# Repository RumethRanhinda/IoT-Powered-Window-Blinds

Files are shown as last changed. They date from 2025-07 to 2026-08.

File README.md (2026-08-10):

# LUMOS – IoT-Powered Automated Window Blinds

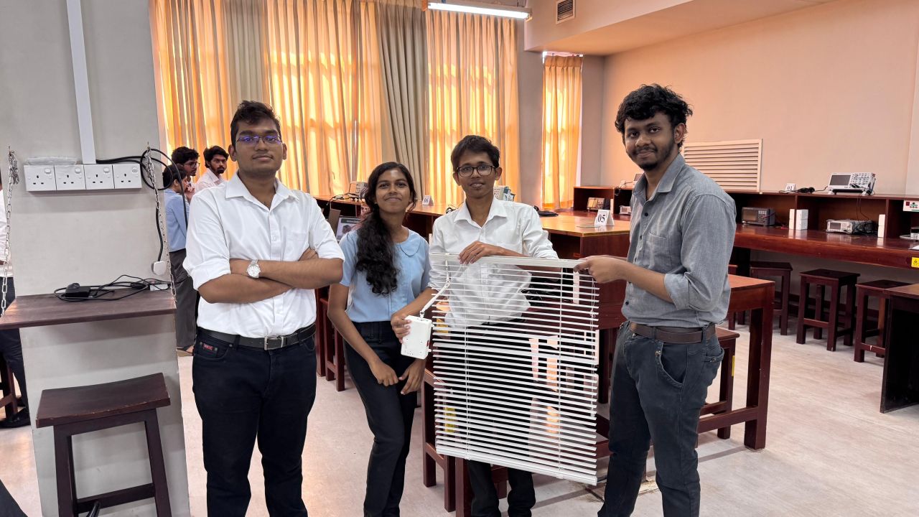
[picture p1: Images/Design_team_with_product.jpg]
Design_team_with_product







**LUMOS** is an automated, light-sensitive smart window blind adjustment system designed to optimize indoor ambient lighting autonomously. Engineered as an accessible and cost-effective alternative to expensive imported motorized blinds, LUMOS continuously monitors ambient lux levels and adjusts the blind tilt angle using a stepper motor and universal joint shaft drive mechanism. It features a Next.js 15 web dashboard with real-time controls, historical data dynamic graphs, and AI-driven insights.

Developed as part of the **EN1190 Engineering Design Project** at the Department of Electronic and Telecommunication Engineering, University of Moratuwa.

---

## Key Features

* **Dual-Sensor Light Averaging**: Uses two BH1750 digital ambient light sensors to compute average lux, preventing false adjustments triggered by temporary light spikes or transient shadows.
* **30-Second Adjustment Cycle**: Periodically evaluates indoor ambient light against user-defined room thresholds and drives the stepper motor to achieve optimal tilt.
* **Universal Joint Drive Mechanism**: A custom-designed 3D-printed connecting shaft featuring dual universal joints (u-joints) transfers motor torque at variable angles from the wall-mounted enclosure to the blind wand.

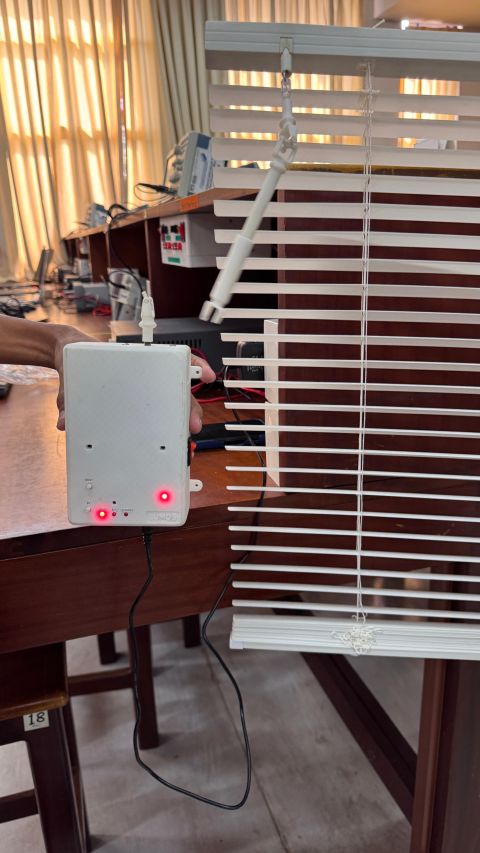
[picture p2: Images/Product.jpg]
Product
  
  
* **Dual Operating Modes**:
  * **Automatic Mode**: Autonomous light sensing and motor control based on target light intensity.
  * **Manual Mode**: Direct web app override using tilt position presets (Fully Open, Mostly Open, Half Closed, Mostly Closed, Fully Closed) or exact angle sliders.
* **IoT Web Dashboard**: Built with Next.js 15, Tailwind CSS, and ShadCN UI, providing real-time data visualizer, custom control toggles, and sleep mode scheduling.

---

## System Architecture

The overall system architecture consists of an ESP32 processing unit reading dual BH1750 sensors over I2C, driving a 28BYJ-48 stepper motor, and communicating bidirectionally with the Next.js web application over Wi-Fi.

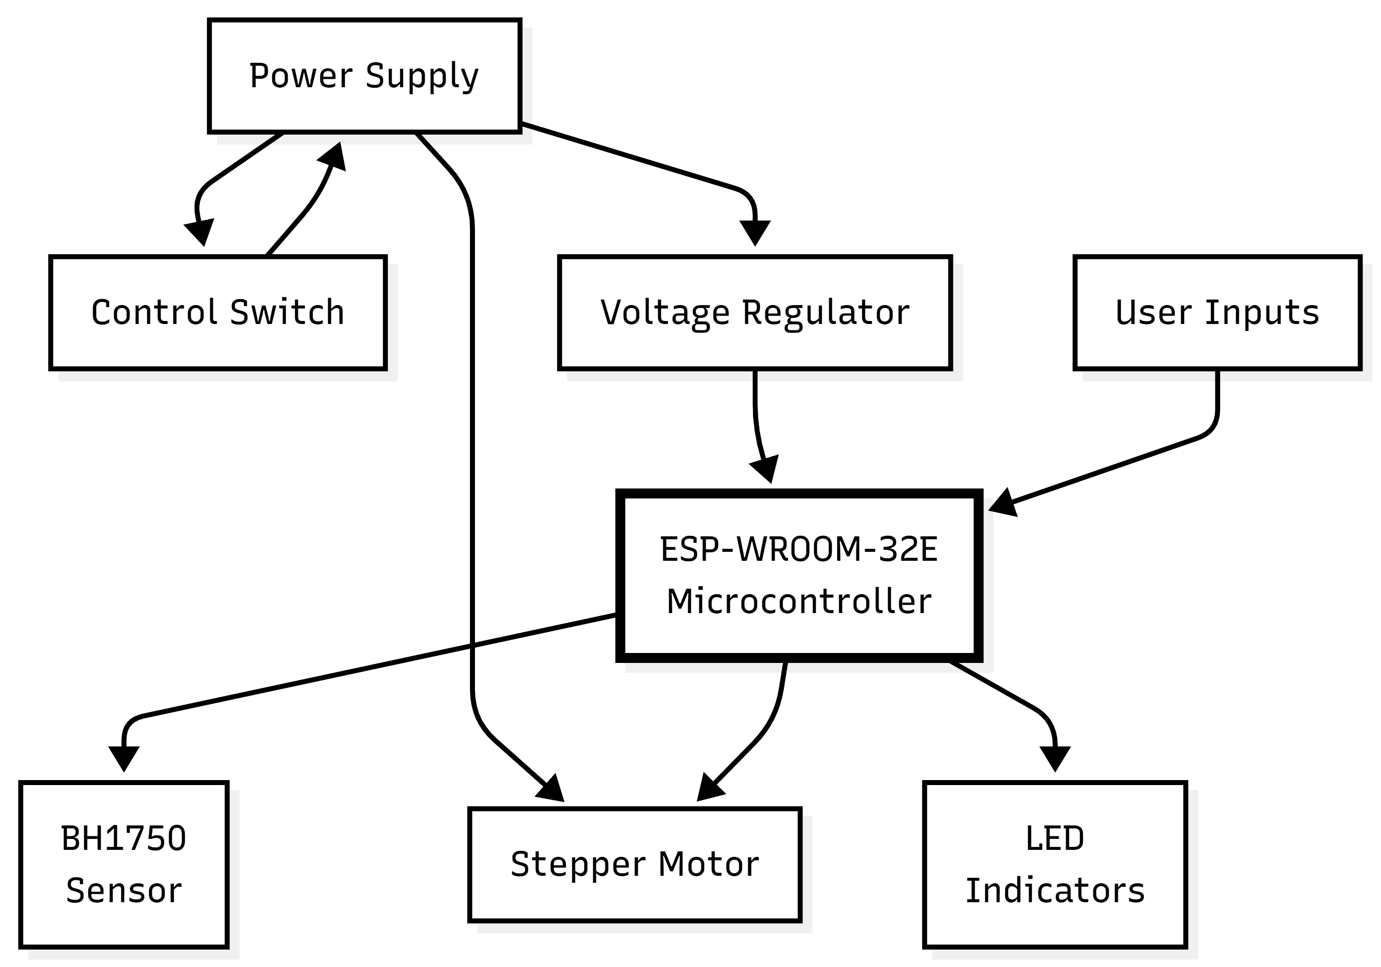
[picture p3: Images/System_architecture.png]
System-Architecture


---

## Hardware Specifications & PCB Design

The custom 2-layer PCB was designed using **Altium Designer** to integrate the ESP32 module, power conditioning components, sensor headers, and motor driving logic into a compact form factor.

| Component | Function / Description |
| :--- | :--- |
| **ESP-WROOM-32E** | Central microcontroller handling sensing, control algorithms, and Wi-Fi connectivity. |
| **BH1750 Sensors (x 2)** | Digital ambient light intensity sensors (Lux) connected via I2C. |
| **28BYJ-48 Stepper Motor** | Provides high-torque, precise angular control of the window blind tilt mechanism. |
| **Voltage Regulator Module** | Regulates 12V DC input down to 3.3V DC for the ESP32 and logic peripherals. |
| **12V Power Pack** | External AC-to-DC power adapter providing primary system power. |
| **Status LEDs & Switches** | Onboard diagnostic indicators (Power, Mode, Sensor State) and manual control buttons. |

### PCB Layout & Assembly
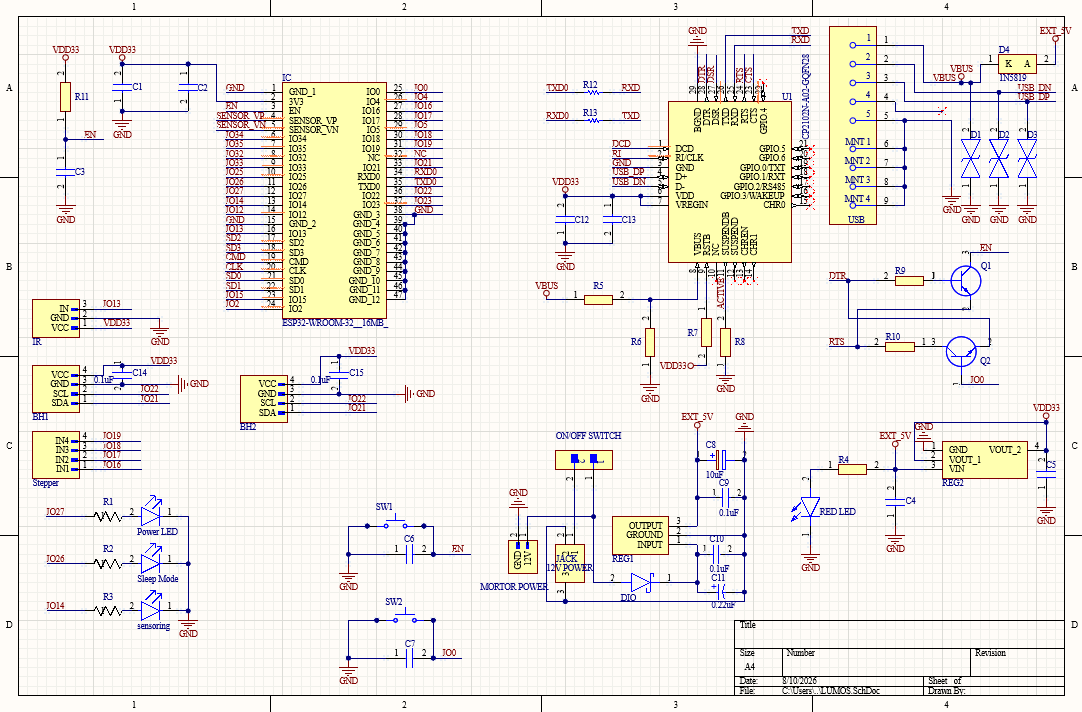
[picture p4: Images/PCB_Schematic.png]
PCB_Schematic

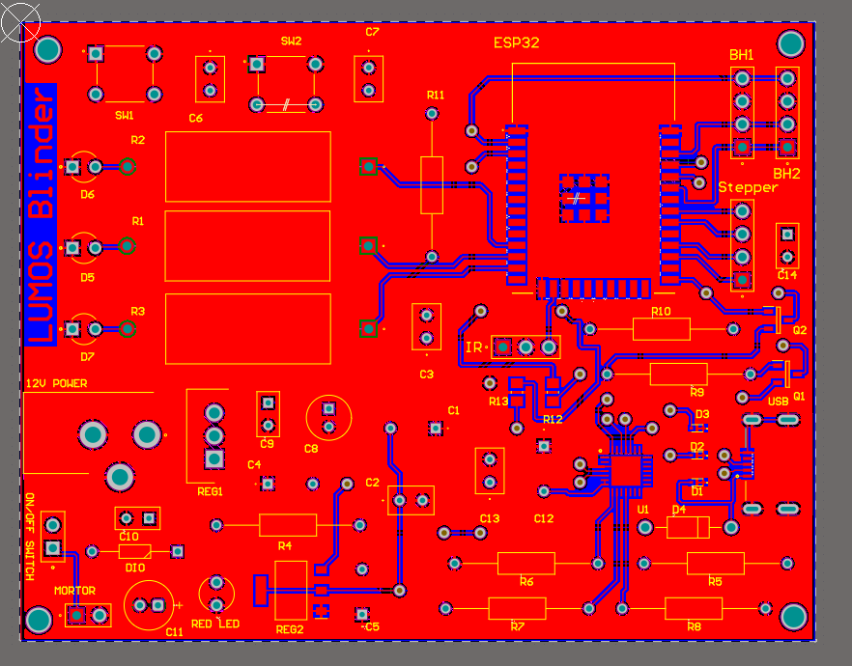
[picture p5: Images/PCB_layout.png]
PCB_layout

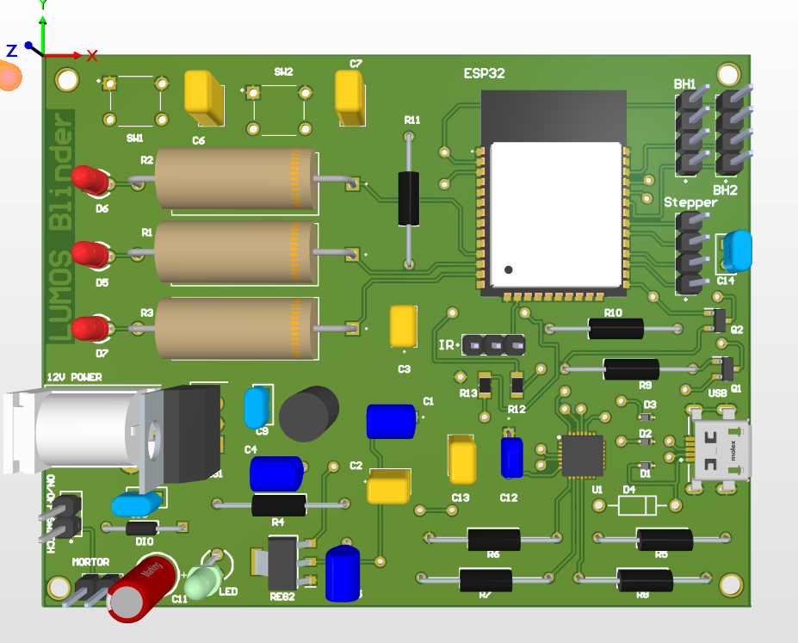
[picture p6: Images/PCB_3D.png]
PCB_3D


---

## Enclosure & Mechanical Design

The enclosure and output shaft mechanism were designed in **SOLIDWORKS** and 3D-printed using PLA.

* **Wall-Mountable Enclosure**: Compact 140 x 50 mm housing with dedicated cutouts for ambient light sensors, status LEDs, override buttons, and power connection.
* **Universal Joint Drive Shaft**: Flexible connecting mechanism utilizing dual u-joints to connect the motor inside the enclosure to the tilt wand on any standard window blind, accommodating variable mounting offsets.

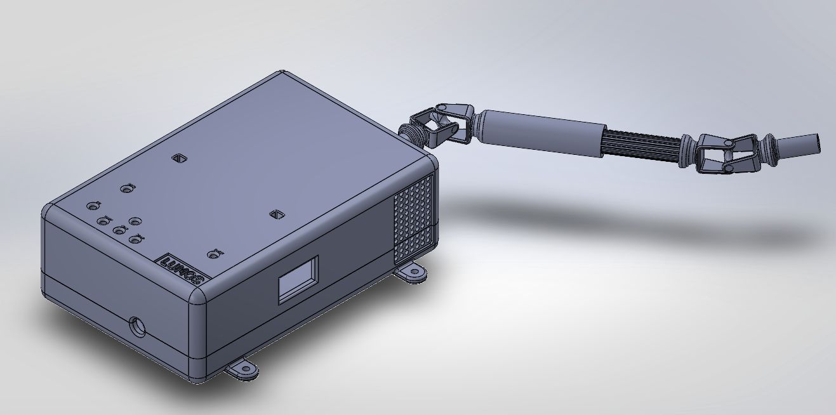
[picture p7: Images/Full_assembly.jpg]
Full_assembly

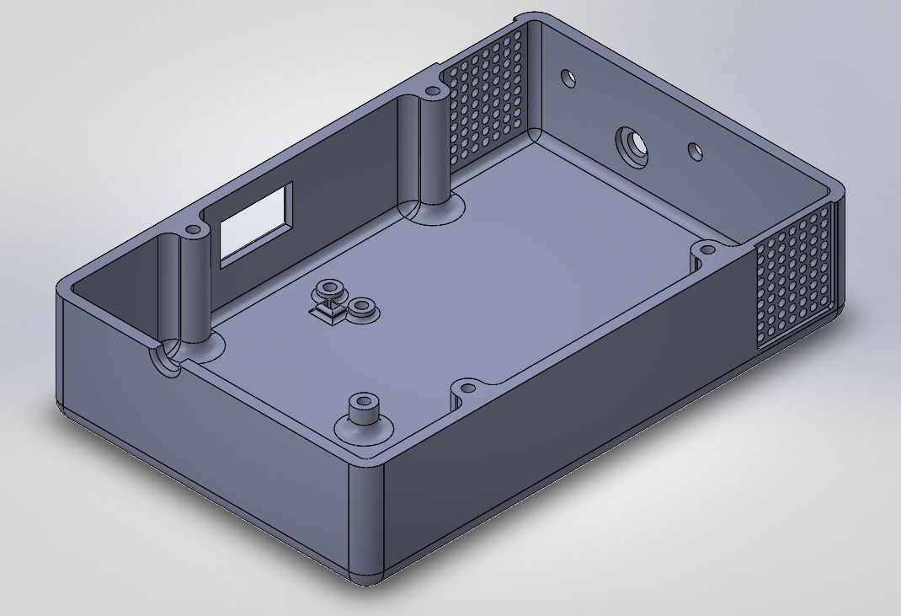
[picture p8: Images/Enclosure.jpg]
Enclosure

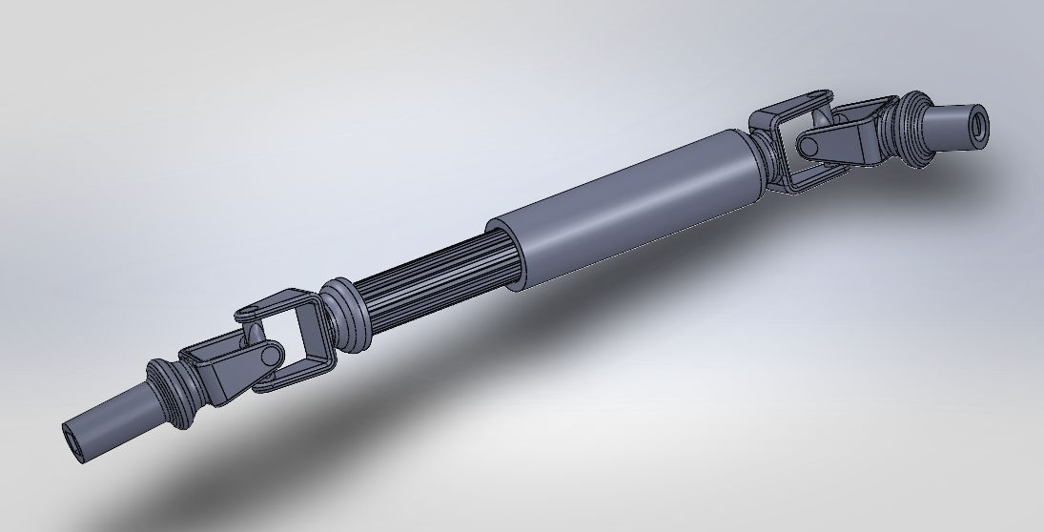
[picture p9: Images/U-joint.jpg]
U-joint


---

## Web Dashboard & Software Architecture

The web application provides interactive monitoring and configuration capabilities.

```text
lumos-web-app/
 ├── app/                  # Next.js 15 App Router pages & API routes
 ├── components/           # React 18 UI components (ShadCN UI)
 ├── lib/                  # Utilities, Firebase Studio & Genkit setup
 └── public/               # Static assets & dashboard icons
```

---

## Getting Started

### Firmware Setup (ESP32)
1. Open the firmware sketch in **Arduino IDE**.
2. Install necessary dependencies via Library Manager:
   * `BH1750`
   * `AccelStepper`
   * `WiFi` / `HTTPClient`
3. Select board **ESP32 Dev Module** and upload the firmware to the ESP32 chip.

---

## Future Improvements

* **Solar Power Integration**: Adding small solar panels and lithium battery storage to eliminate reliance on grid power.
* **Multi-Blind Synchronization**: Controlling and grouping multiple blind controllers across larger commercial spaces.
* **Expanded Blind Mechanism Compatibility**: Adapting mechanical adapters to support vertical blinds, roller shades, and curtain tracks.

---

## Authors & Acknowledgments

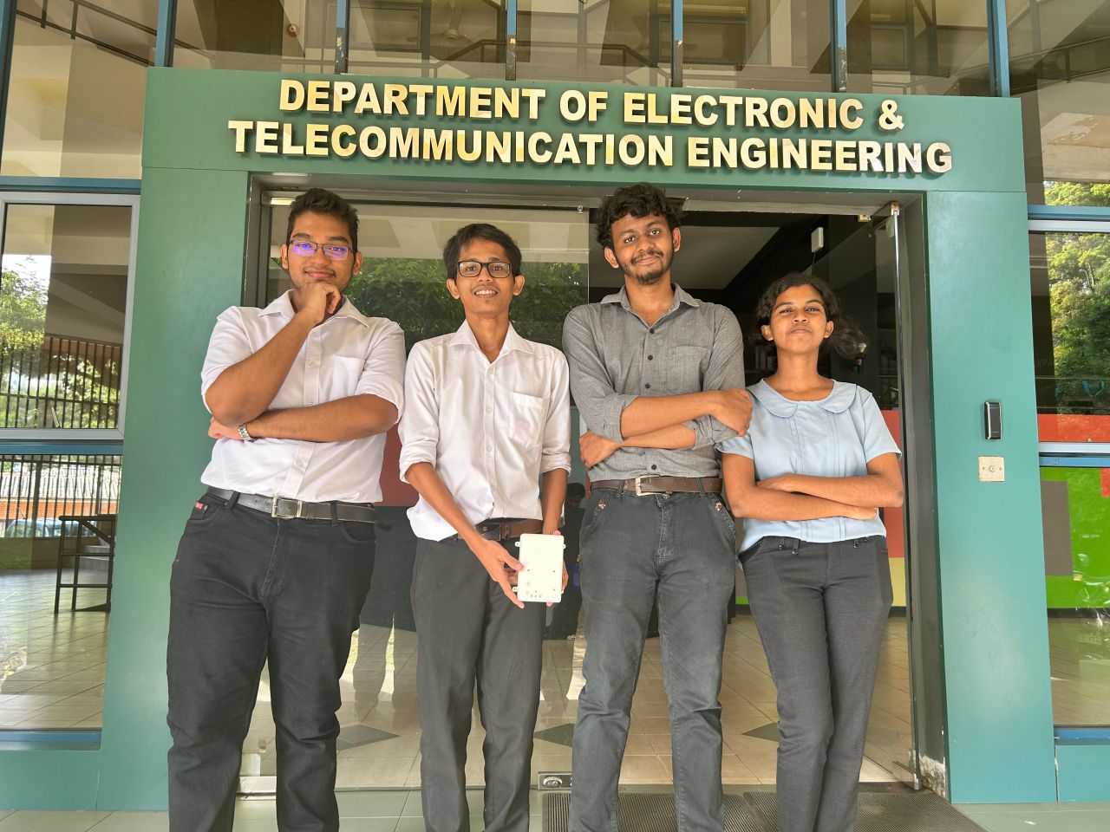
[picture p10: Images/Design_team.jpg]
Design_team


* **Team LUMOS** (Department of Electronic & Telecommunication Engineering, University of Moratuwa): *(From Left to Right)*  
  * Samarasinghe S.M.R.R. – Enclosure Design & Optimization, Mechanical CAD, Debugging
  * Eranga W.A.O. – Circuit & PCB Design, Microcontroller Programming, Web App Design
  * Gamage S.K. – Hardware Selection, Survey Analysis, Presentation
  * Tharushika G.K.E. – Product Assembly, Market Analysis, Costing

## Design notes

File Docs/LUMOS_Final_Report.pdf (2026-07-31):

## University of Moratuwa

## Faculty of Engineering

## Department of Electronic & Telecommunication

## Engineering

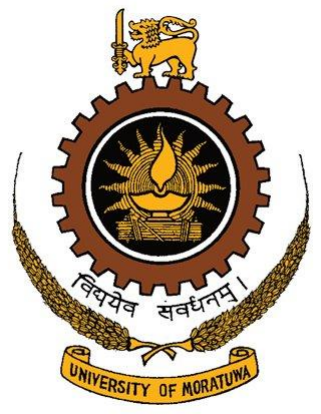
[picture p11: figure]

## EN 1190: Engineering Design Project

## Team LUMOS

## Automatic Window Blinds

### Group Members

Index No | Name
230175U | Eranga W.A.O.
230195F | Gamage S.K.
230566U | Samarasinghe S.M.R.R.
230636K | Tharushika G.K.E.

## Content

### 1. Problem Description

1.1. Problem
1.2. Expected Goal
1.3. Solution
1.4. Justification and Selection

### 2. Product Feasibility

2.1. Technical Feasibility
2.2. Hardware Feasibility
2.3. Software Feasibility

### 3. Product Applications 4. Product Specifications 5. Product Architecture

5.1. Block diagram

### 6. Enclosure Design

6.1. Initial Sketches
6.2. Final Sketch
6.3. Connecting Mechanism (Shaft)
6.4. Top View
6.5. Bottom View

### 7. PCB Design 8. Final Product 9. Market Analysis 10. Cost Analysis and Pricing

10.1. Project Budget with BOQ
10.2. Pricing Justification

### 11. Future Improvements 12. Contribution Report

## 1. Problem Description

### 1.1. Problem

Manual window blinds are still widely used in Sri Lanka, but they present several practical challenges. Elderly, disabled, and physically unwell individuals often struggle to adjust blinds on their own. In large-scale settings such as hotels, offices, and institutions with numerous windows, manual adjustment becomes a time-consuming and labor-intensive task. Additionally, in environments like greenhouses, laboratories, museums and material storage facilities, where maintaining ideal lighting conditions is crucial, manual blinds fail to provide consistent control.

Although motorized and automatic window blind systems with light sensors exist internationally, they are not manufactured locally in Sri Lanka. The limited options available in the local market are imported products that are often prohibitively expensive and not suited for widespread or affordable adoption. As a result, there is a clear gap in the availability of cost-effective, smart window blind solutions that fulfil local needs.

### 1.2. Expected Goal

Our goal is to provide a practical and accessible solution for individuals who face difficulties in manually operating window blinds, such as the elderly, disabled, or physically unwell, as well as for environments where efficient light control is essential. We aim to simplify and automate the process of adjusting blinds using light-sensing technology, allowing users to maintain optimal indoor lighting conditions effortlessly, without the need for manual labor, technical expertise, or expensive infrastructure

### 1.3. Solution

Our solution is an Automatic Light-Sensitive Window Blind System designed to adjust the tilt of blinds based on the ambient light level in the room. During installation, users can specify their preferred lighting levels for each room, accommodating different needs such as workspaces, bedrooms, or specialized environments like greenhouses. The system then operates autonomously, maintaining optimal lighting without the need for manual adjustment. Unlike traditional systems, our product is designed to be affordable and user-friendly. We also offer comprehensive after-sales support, including assistance with installation, routine maintenance, and technical guidance to ensure smooth operation over time, which is impossible to get when shipping from overseas.

### 1.4. Justification of Selection

The lack of accessible and reliable automated window blind systems presents a practical issue in Sri Lanka, especially for individuals with physical limitations and in environments where precise lighting control is essential. Currently, the market relies heavily on imported motorized blind systems, which are not only expensive but also prone to technical failures. Moreover, these systems are often limited to premium establishments and are largely unavailable to the general public.

Through discussions with local window blind sellers and industry professionals, we identified a significant gap in the Sri Lankan market for an affordable, durable, and locally supported automated window blind solution. Sellers expressed a willingness to collaborate, noting that a reliable, cost-effective alternative would benefit both residential and commercial customers. Our proposed system directly addresses these concerns by offering a customizable, light-sensitive solution backed by local after-sales support.

## 2. Product Feasibility

### 2.1. Technical Feasibility

We have successfully developed a technically viable prototype using reliable and accessible components. To measure indoor light intensity, we used two BH1750 light sensors to obtain an average reading, which helps minimize the impact of sudden light spikes and ensures accurate decision-making. The system is controlled by an ESP-WROOM-32E microcontroller, which processes sensor inputs and adjusts the blinds accordingly.

For actuation, we utilized the 28BYJ-48 stepper motor, which precisely controls the angle of the window blinds. The system is powered through an AC supply; regulated via a 12V power pack to ensure consistent and stable performance and a voltage regulator to maintain a stable voltage at 3.3V. All necessary components were acquired, and the integration was completed successfully. The enclosure and the connecting shaft were 3D printed using PLA. We designed and assembled the circuit ourselves, including custom soldering work and mechanical alignment for the blind mechanism.

### 2.2. Hardware Feasibility

The hardware components we used are

- ESP-WROOM-32E Chip
- BH1750 Light Intensity Sensors
- Voltage Regulator Module
- Stepper Motor 28BYJ-48
- LED Indicators
- 12V Power Pack

### 2.3. Software Feasibility

Software | Programming Language | Purpose
Arduino | C++ | To Program the ESP 32 chip
SOLIDWORKS | - | To Design the Enclosure
Firebase Studio | React | To Create the Web App

## 3. Product Applications

The main application of the automatic light-sensitive window blind system is to maintain optimal indoor lighting conditions without manual intervention. By continuously monitoring the ambient light levels using dual BH1750 sensors, the system automatically adjusts the tilt angle of the blinds to match the user-defined brightness preferences set during installation. This ensures a consistent and comfortable lighting environment across different rooms, while also improving energy efficiency and reducing the need for frequent manual adjustments, especially beneficial for elderly, disabled individuals, and large-scale settings such as hotels and offices.

LUMOS Blinder Web Application

The LUMOS Smart Blind Web application is connected to the device via Wi-Fi. It displays real-time ambient light levels and blind angles through an interactive dashboard. Users can switch between automatic and manual control modes, view historical data through dynamic charts, and receive AI-generated insights about lighting patterns.

The app also allows configuration of system settings like sensing intervals and includes a responsive UI with mock authentication for user-specific access.

Core Technologies

- Frontend Framework: Next.js 15 with the App Router, enabling a modern, server-first web application with optimized performance.
- UI Library: React 18 for building interactive and stateful user interface components.
- Styling: Tailwind CSS for a utility-first styling approach, combined with ShadCN UI for a pre-built, accessible, and themeable component library.
- Artificial Intelligence: Google's Genkit framework to integrate generative Al, powering the "Al Assistant" feature for data analysis and insights.
- Language: TypeScript for type safety, improved developer experience, and more maintainable code.

Key Functionalities

- Real-time loT Dashboard: The application features a live dashboard that simulates real-time data from lot sensors (lux sensors) and actuators (window blinds).
- Dynamic Data Visualization: A responsive line chart visualizes historical sensor and blind angle data, updating dynamically to reflect system changes.
- Dual Control Modes:
1. Automatic Mode: The system intelligently adjusts the blind angle based on simulated ambient light levels, mimicking a real- world automated smart home device.
2. Manual Mode: Users can disable the automatic system and take direct control of the blinds using a slider and preset position buttons.
- Al-Powered Insights: An "Al Assistant" uses a Genkit flow to analyze the recent history of sensor data and blind movements, providing users with easy-to-understand summaries and insights about the system's behavior.
- System Configuration: Users can configure system parameters, such as the Sensing Interval, to simulate changing the device's data reporting frequency. A "Sleep Mode" toggle is also included as a UI element.
- Responsive and Modern UI: The user interface is designed to be fully responsive, adapting seamlessly to desktop, tablet, and mobile screen sizes. It also includes a dark/light mode theme toggle for user preference.
- Mock Authentication: The app includes a simulated user authentication flow to demonstrate how UI elements (like controls) can be enabled or disabled based on user signin status.

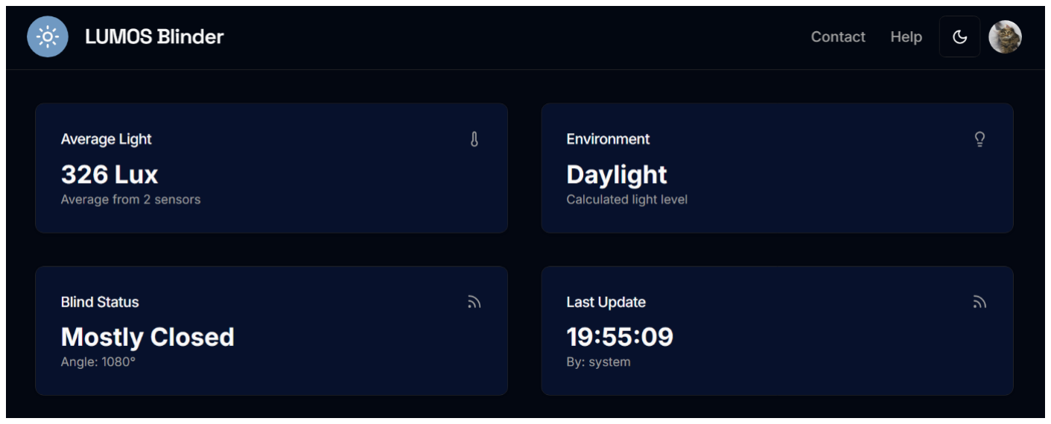
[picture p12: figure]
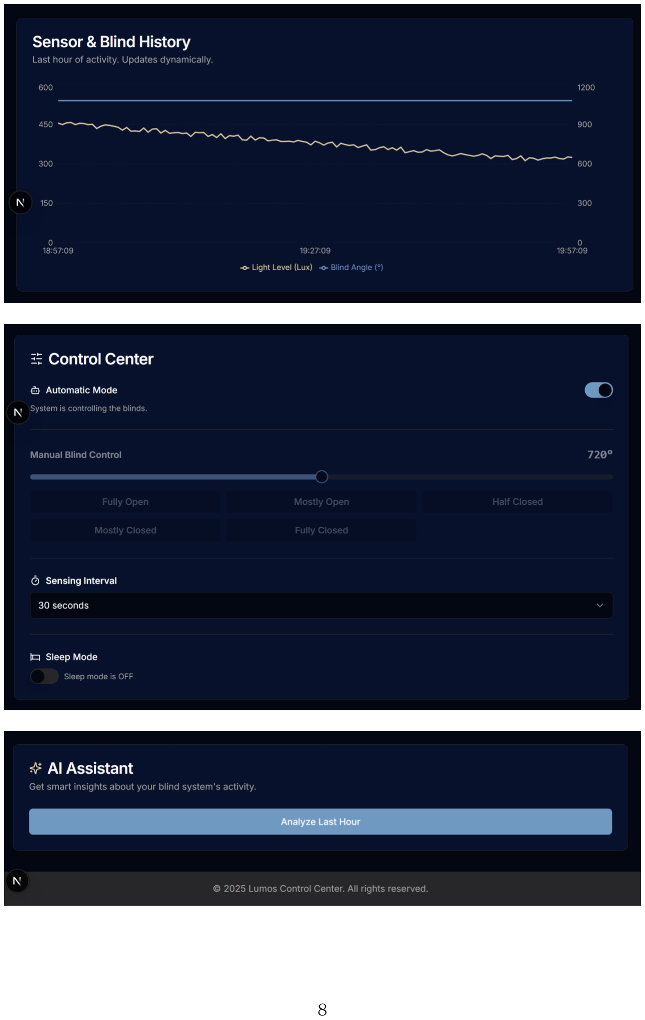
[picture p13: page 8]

## 4. Product Specifications

- Type: Automatic Window Blind Controller with Light Sensors
- Synonyms: Smart Blind Controller, Light-Sensitive Blinds, Motorized Smart Blind Adjustment System
- Control Method: Light Intensity-Based Automatic Adjustment
- Power Supply: 12V DC via AC Power Pack
- Dimensions: 140x50 mm
- Weight: 150g
- Connectivity: Wired
- Installation: Wall-Mountable Control Box
- User Settings: Customizable Brightness Thresholds per Room at Installation

## 5. Product Architecture

- Power Supply - The system is powered through a 12V DC supply using an external AC power pack.
- ESP 32 chip - The ESP-WROOM-32E microcontroller is used to process real time light intensity data from the sensors and control the stepper motor accordingly. It handles averaging, decision making logic, and motor control.
- Voltage Regulator - Regulates the input voltage to 3.3V for the ESP32 to operate reliably.
- Light Sensors - Two BH1750 digital light sensors are used to measure indoor light intensity. Averaging the readings from both sensors helps avoid errors caused by sudden light fluctuations and improves the accuracy of blind adjustment.
- Motor - The 28BYJ-48 stepper motor is used to adjust the tilt angle of the window blinds smoothly and precisely.
- Web App – Connected to the device via Wi-Fi, displays light levels and blind angles, and allows the users to switch between manual and automatic control modes.
5.1. Block Diagram

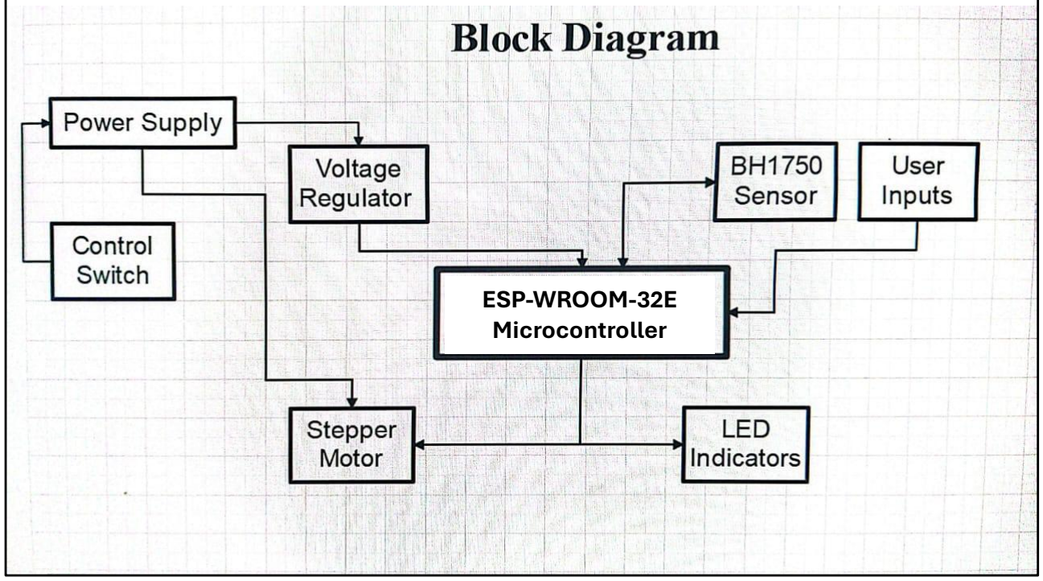
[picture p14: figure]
ESP-WROOM-32E Microcontroller

## 6. Enclosure Design

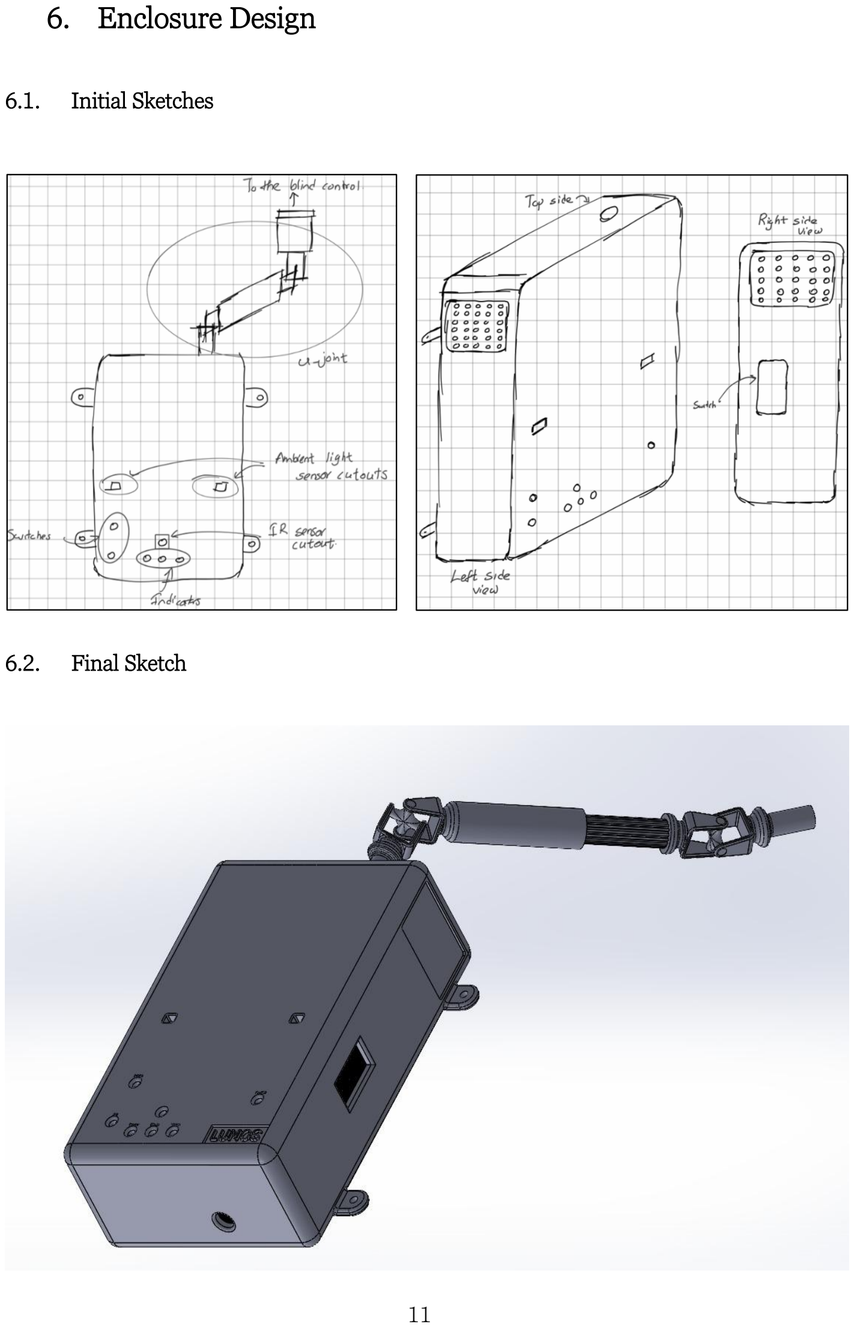
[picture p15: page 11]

6.1. Initial Sketches
6.2. Final Sketch

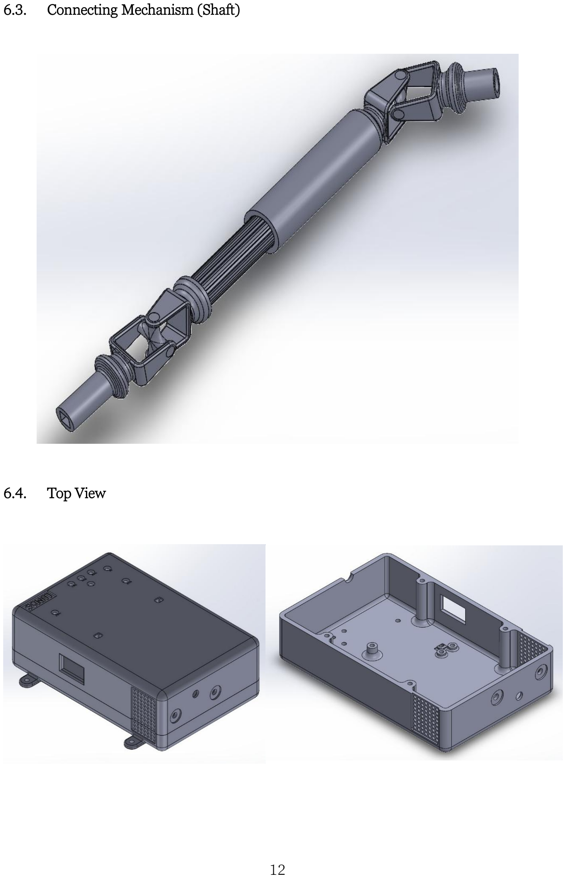
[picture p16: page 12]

6.3. Connecting Mechanism (Shaft)
6.4. Top View

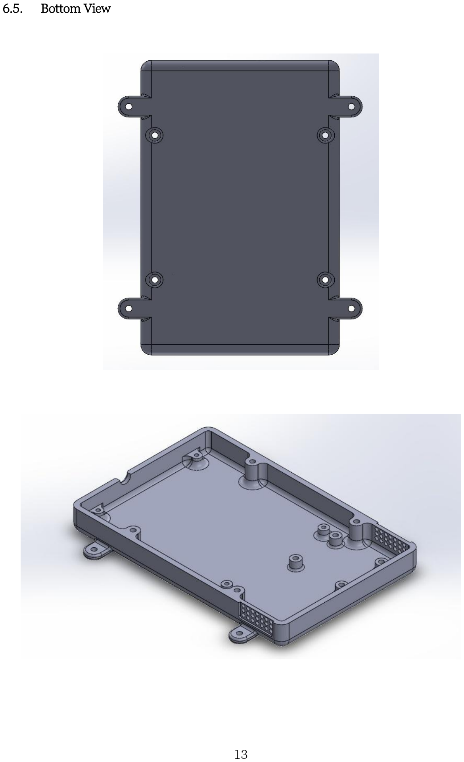
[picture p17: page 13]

6.5. Bottom View

## 7. PCB Design

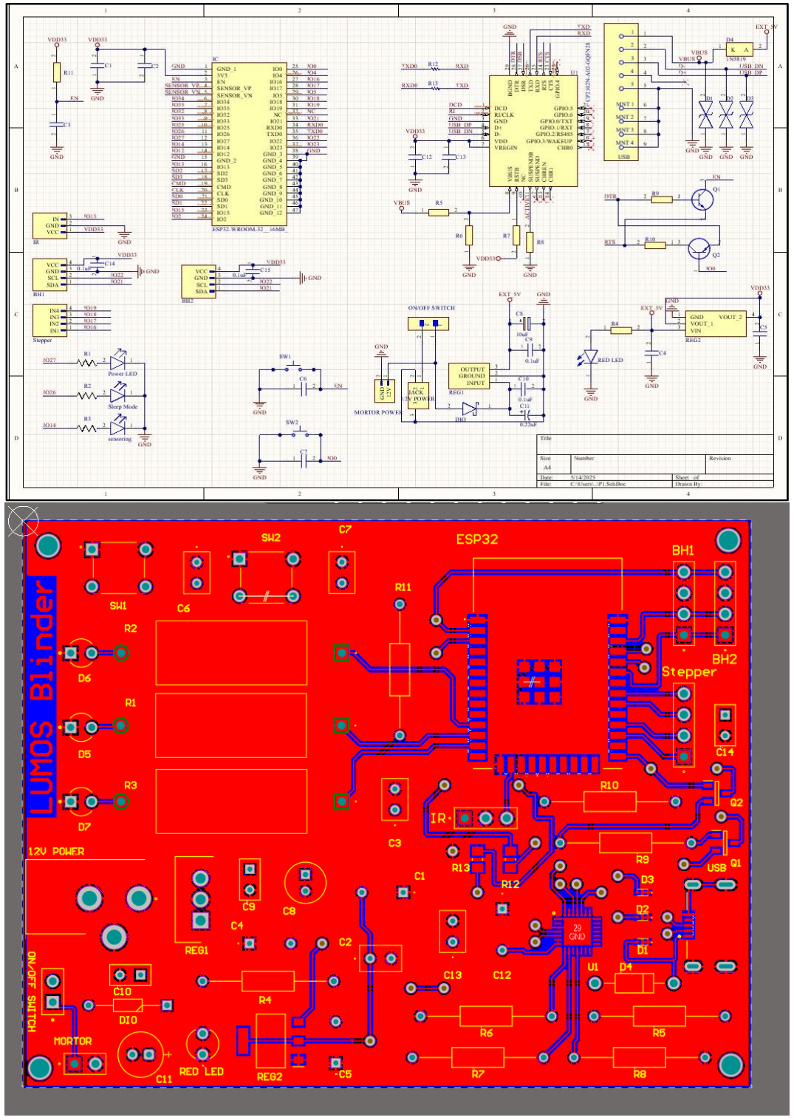
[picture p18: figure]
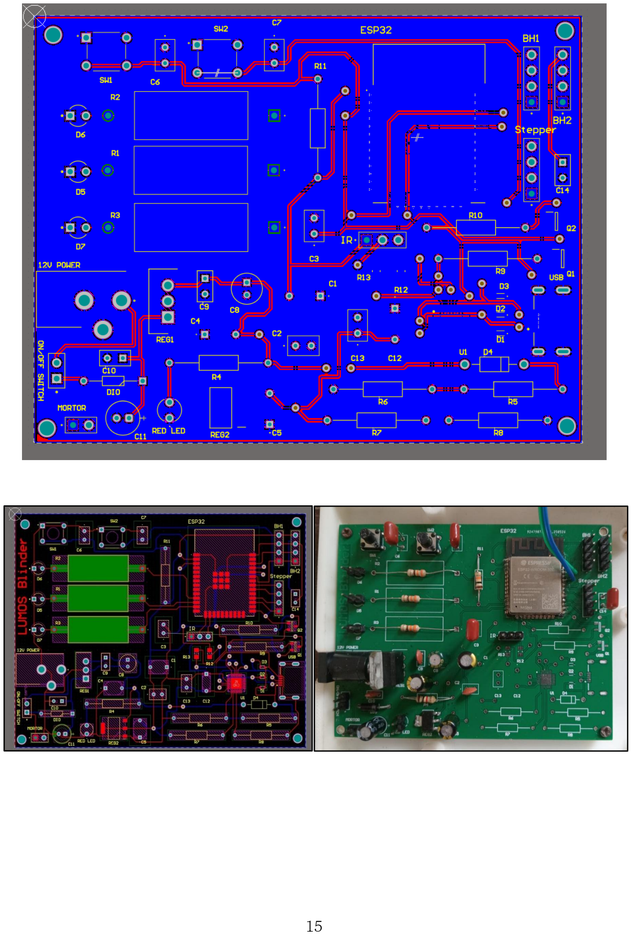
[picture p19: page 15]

## 8. Final Product

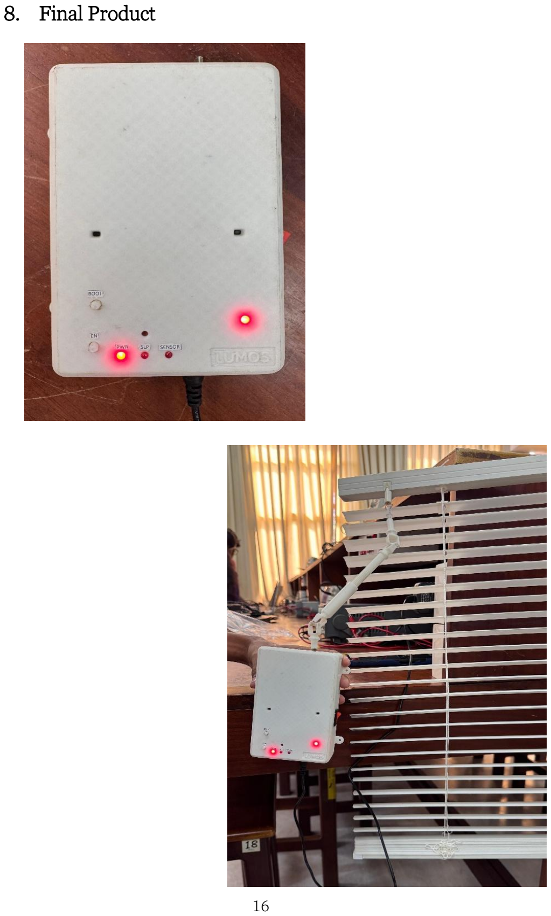
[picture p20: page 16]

## 9. Market Analysis

The smart blind automation market is gaining momentum globally due to increasing demand for energy efficiency, convenience, and smart home integration. Automated blind systems equipped with light sensors offer benefits such as optimizing natural lighting, reducing air conditioning use, and improving indoor comfort, all without user intervention. These systems are particularly useful in homes, offices, hospitals, and hotels, and also support accessibility for elderly or disabled individuals who may find manual blind operation difficult.

Our target audience includes environmentally conscious homeowners, tech-savvy consumers, corporate offices, hospitality businesses, and interior designers who seek modern, minimal-effort solutions. Possible business models for our product include directto-consumer sales, partnerships with hardware retailers and interior design firms, and even customized B2B deals for bulk deployment in institutions like hotels or hospitals.

However, we identified that there are no local manufacturers offering such systems in Sri Lanka, despite the rising interest in home automation. As a result, consumers must rely on international sellers, with base prices starting around LKR 21,000, but reaching up to LKR 33,000 to 36,000 after adding shipping and customs fees. Additionally, most of these imported products lack local warranty, maintenance, or after-sales service—resulting in inconvenience and higher lifetime costs.

This clear market gap highlights a strong opportunity for a locally developed, cost-effective blind automation solution with light sensoring that can be easily installed without replacing existing blinds. Challenges such as educating the public, building brand credibility, and competing with well-established global brands remain, but overcoming these barriers will be essential for capturing a significant share of this emerging market in Sri Lanka.

## 10. Cost Analysis and Pricing

10.1. Project Budget with BOQ
EXPENSE | Unit Price (Rs.) | Quantity | COST (Rs.)
Enclosure | 4,850.00 | 1 | 4,850.00
PCB | 3,360.00 | 1 | 3,360.00
ESP-WROOM-32E Chip | 1,000.00 | 1 | 1,000.00
Stepper Motor 28BYJ-48 | 600.00 | 1 | 600.00
BH1750 Sensors | 125.00 | 2 | 250.00
RLC components & Wiring | | | 400.00
Connector Shaft Mechanism | 750.00 | 1 | 750.00
Voltage Regulator + USB module | | | 500.00
12V Power Pack | 500.00 | 1 | 500.00
Misc. | | | 200.00
TOTAL | | | 12,410.00
10.2. Pricing Justification

The selling price for the product was determined by first calculating the manufacturing cost, which totals approximately Rs. 12,410 per unit. This includes all electronic components, motor, power supply, enclosure, and assembly. A reasonable markup was then applied to ensure profitability, after-sales service capability, and to account for future reductions in cost through mass production.

Considering these factors, the estimated selling price was set at Rs. 18,000 to Rs. 20,000, which remains significantly lower than the Rs. 33,000–36,000 required to import similar products. This pricing provides customers with savings of up to Rs. 20,000, while also offering local support and maintenance—something that imported alternatives lack. This ensures both affordability and long-term usability for Sri Lankan consumers.

## 11. Future Improvements

Introduction to Solar Power for Eco-Friendliness

Implementing solar panels to power the system, reducing dependence on grid electricity and promoting sustainability.

Integration of IoT Features

Adding Wi-Fi or cloud connectivity for remote control, real-time monitoring, and integration with smart home systems.

Multiple Blind Synchronization for Efficiency

Enabling control of multiple blinds simultaneously to maintain uniform lighting across large rooms or buildings.

Design Configurations for Other Types of Blinds

Adapting the system to support vertical blinds, roller blinds, and curtain mechanisms for broader compatibility

## 12. Contribution Report

Member | Tasks
Eranga W.A.O. (230175U) | Circuit & PCB Design Microcontroller Programming & Testing Web App Design
Gamage S.K. (230195F) | Product Idea, Hardware Selection Survey Analysis & Presentation
Samarasinghe S.M.R.R. (230566U) | Enclosure Design & Optimization Product Testing & Debugging
Tharushika G.K.E. (230636K) | Product Assembly & Testing Market Analysis and Budget Calculation

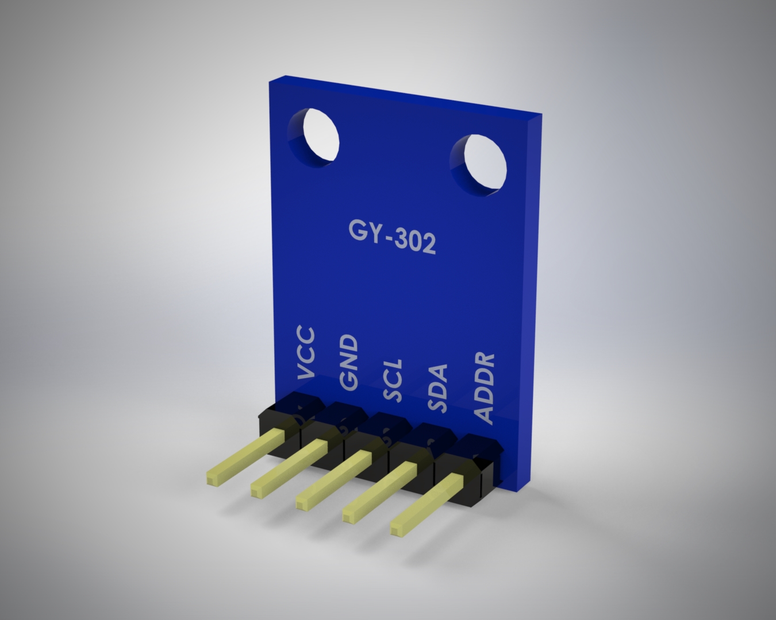
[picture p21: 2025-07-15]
SOLIDWORKS Files/Enclosure/bh1750-module/photos/Rear.jpg

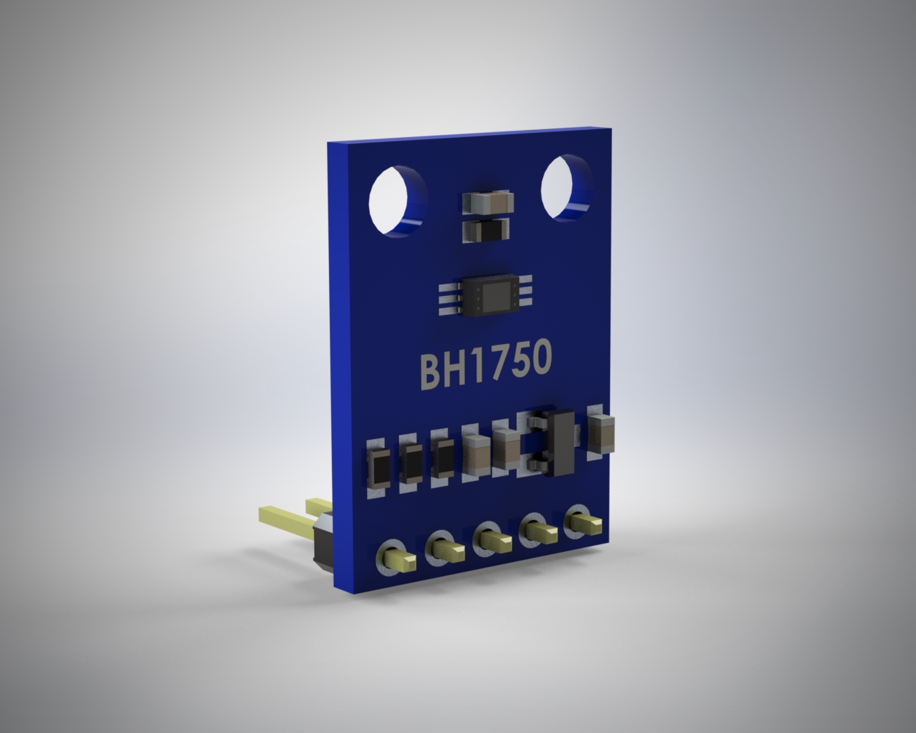
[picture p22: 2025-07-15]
SOLIDWORKS Files/Enclosure/bh1750-module/photos/Front.jpg

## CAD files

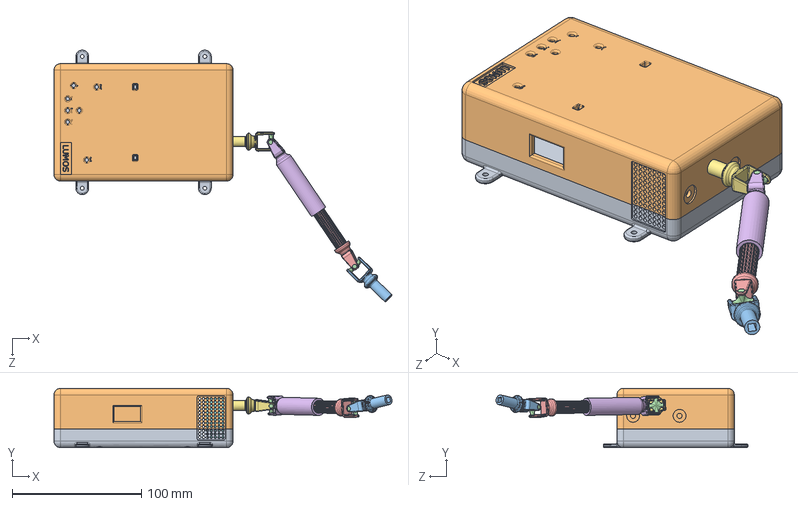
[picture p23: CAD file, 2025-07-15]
SOLIDWORKS Files/Full Assembly.SLDASM
261.9 x 46.0 x 195.1 mm
enclosurebottom
enclosuretop
rwhubshaft2
ujoint x 2
rwinnershaft
rwoutershaft
rwsprocketshaft
28BYJ-48

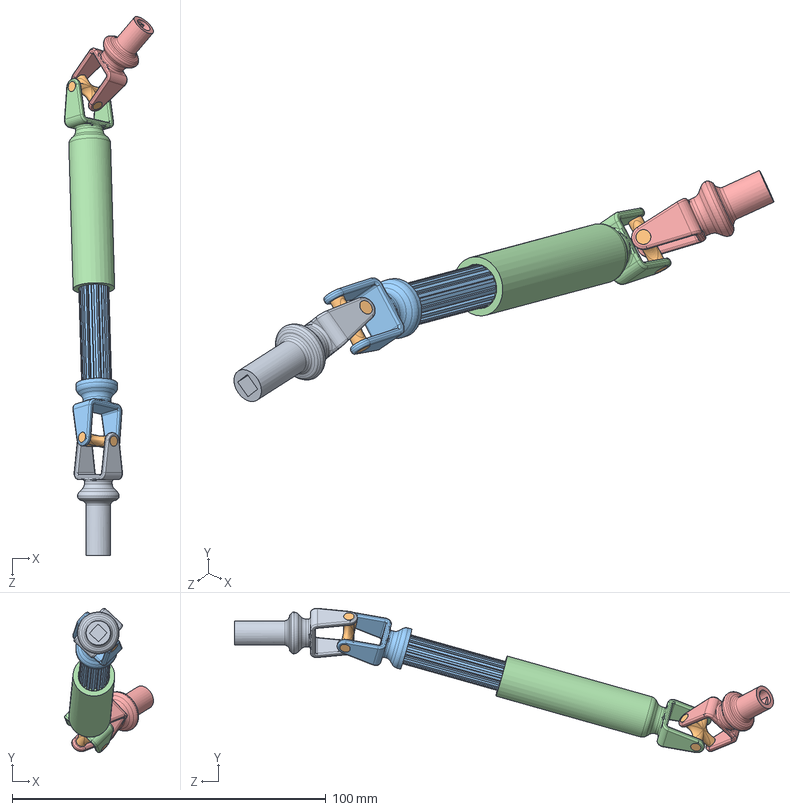
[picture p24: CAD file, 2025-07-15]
SOLIDWORKS Files/U-shaft/pivotslidingshaft-Assembly.SLDASM
28.4 x 46.0 x 171.9 mm
rwhubshaft2
ujoint x 2
rwinnershaft
rwoutershaft
rwsprocketshaft

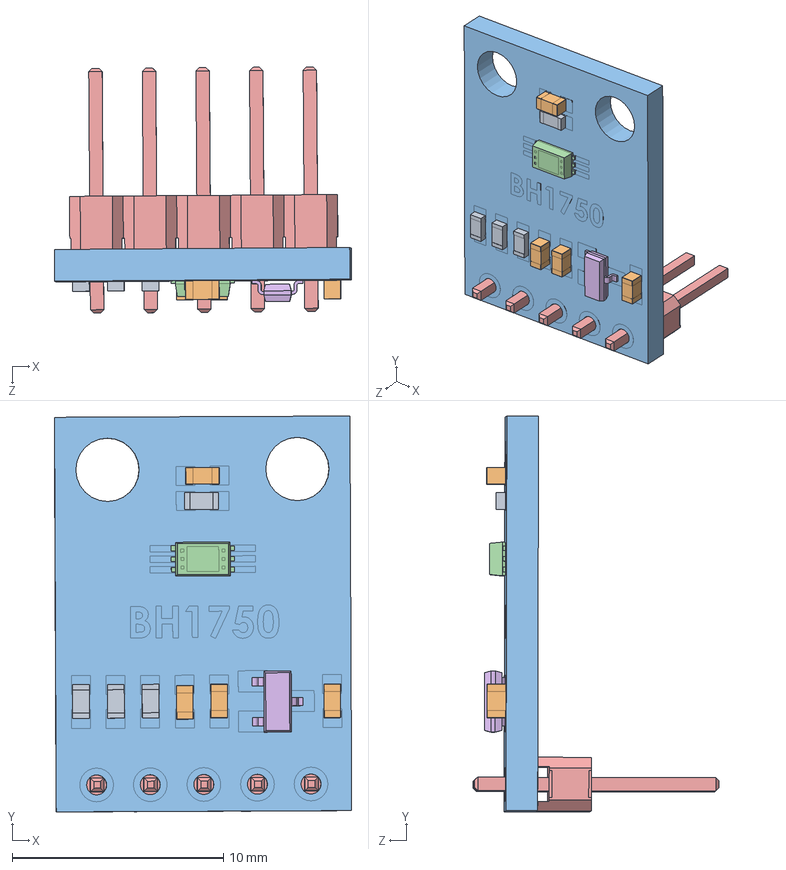
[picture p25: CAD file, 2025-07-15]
SOLIDWORKS Files/Enclosure/bh1750-module/Assign/BH1750_with_connector.SLDASM
14.1 x 18.8 x 11.7 mm
r_0603 x 4
cap_0603 x 4
BH1750_board
BH1750
PLS-5
SOT-23-3

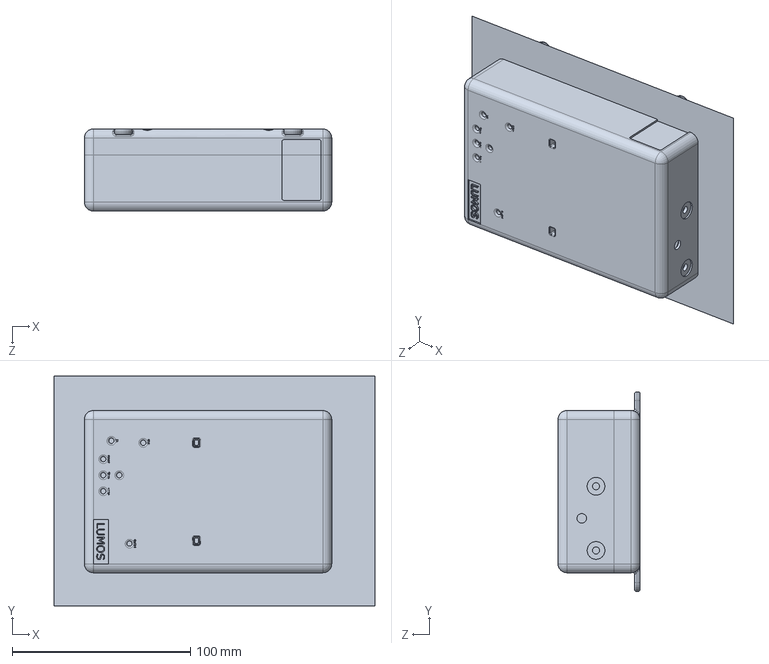
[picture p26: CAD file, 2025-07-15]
SOLIDWORKS Files/Enclosure/Enclosure-Full Assembly.SLDASM
180.0 x 128.9 x 46.0 mm

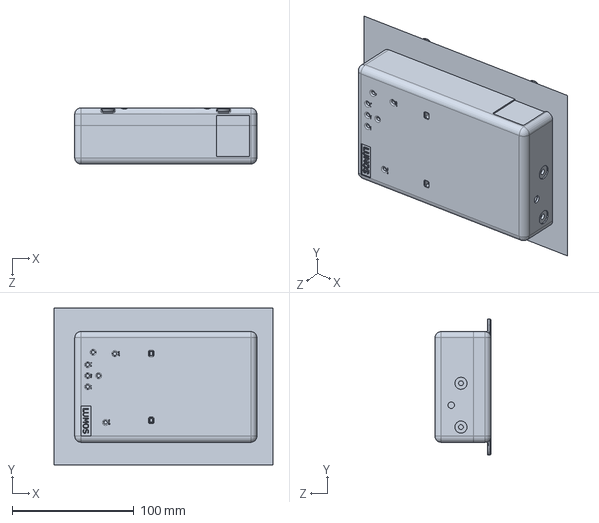
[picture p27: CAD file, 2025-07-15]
SOLIDWORKS Files/Enclosure/Enclosure_whole.SLDPRT
180.0 x 128.9 x 46.0 mm

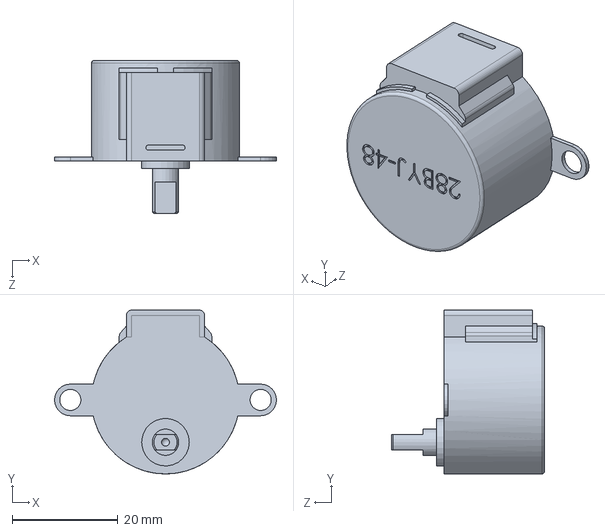
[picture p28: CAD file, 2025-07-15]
SOLIDWORKS Files/Enclosure/28byj-48-4-stepper-motor/28BYJ-48.SLDPRT
42.0 x 31.0 x 29.0 mm

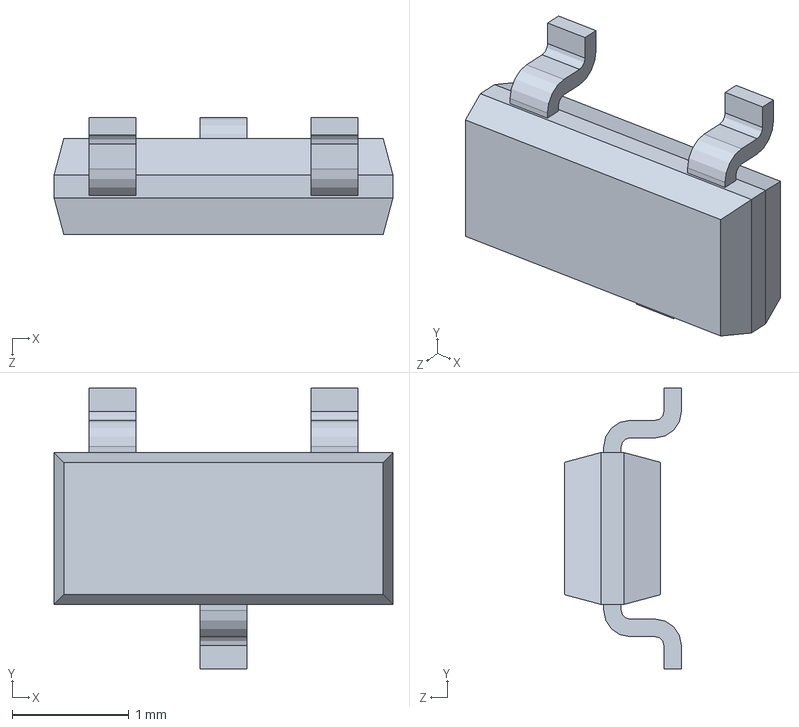
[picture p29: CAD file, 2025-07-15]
SOLIDWORKS Files/Enclosure/bh1750-module/Assign/SOT-23-3.SLDPRT
2.90 x 2.40 x 1.00 mm

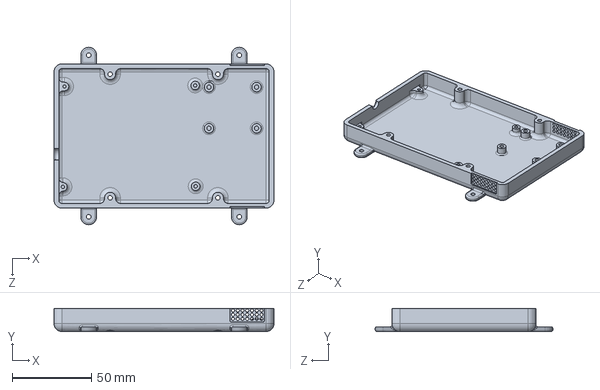
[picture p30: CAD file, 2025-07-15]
SOLIDWORKS Files/Enclosure/enclosurebottom.SLDPRT
138.8 x 14.5 x 112.0 mm

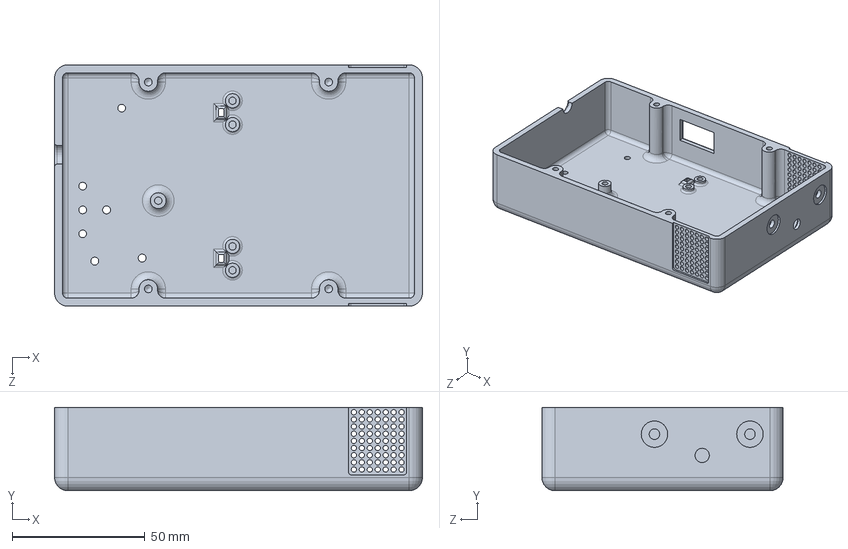
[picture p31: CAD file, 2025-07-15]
SOLIDWORKS Files/Enclosure/enclosuretop.SLDPRT
138.8 x 31.5 x 91.0 mm

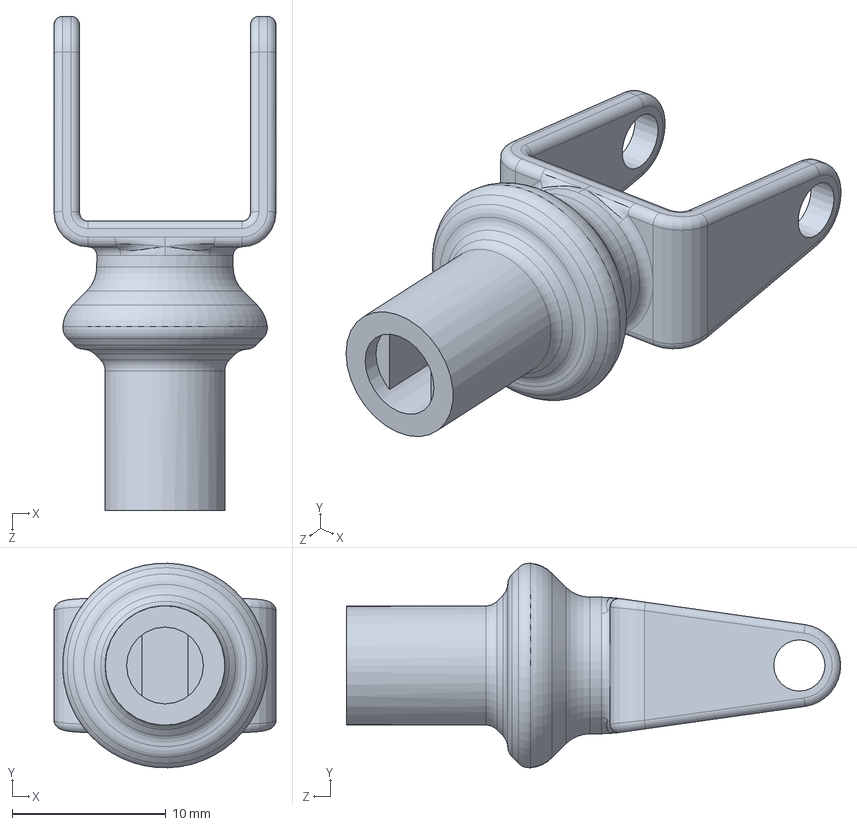
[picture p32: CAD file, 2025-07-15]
SOLIDWORKS Files/U-shaft/rwsprocketshaft.SLDPRT
14.4 x 13.3 x 32.2 mm

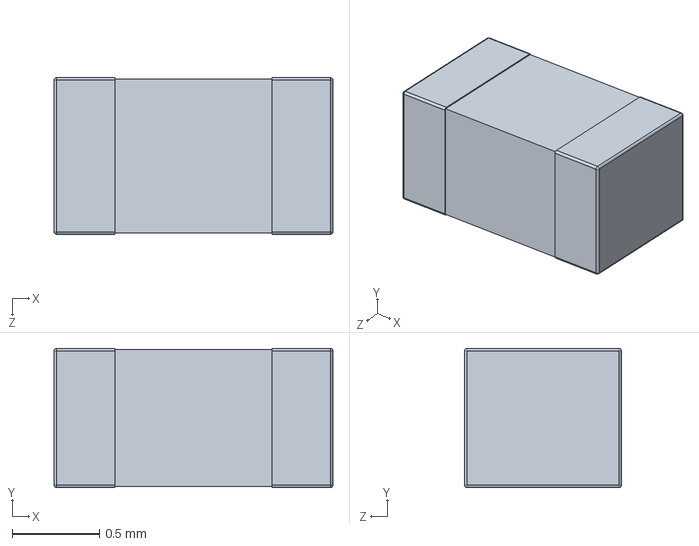
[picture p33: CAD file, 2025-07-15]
SOLIDWORKS Files/Enclosure/bh1750-module/Assign/cap_0603.SLDPRT
1.60 x 0.8 x 0.9 mm

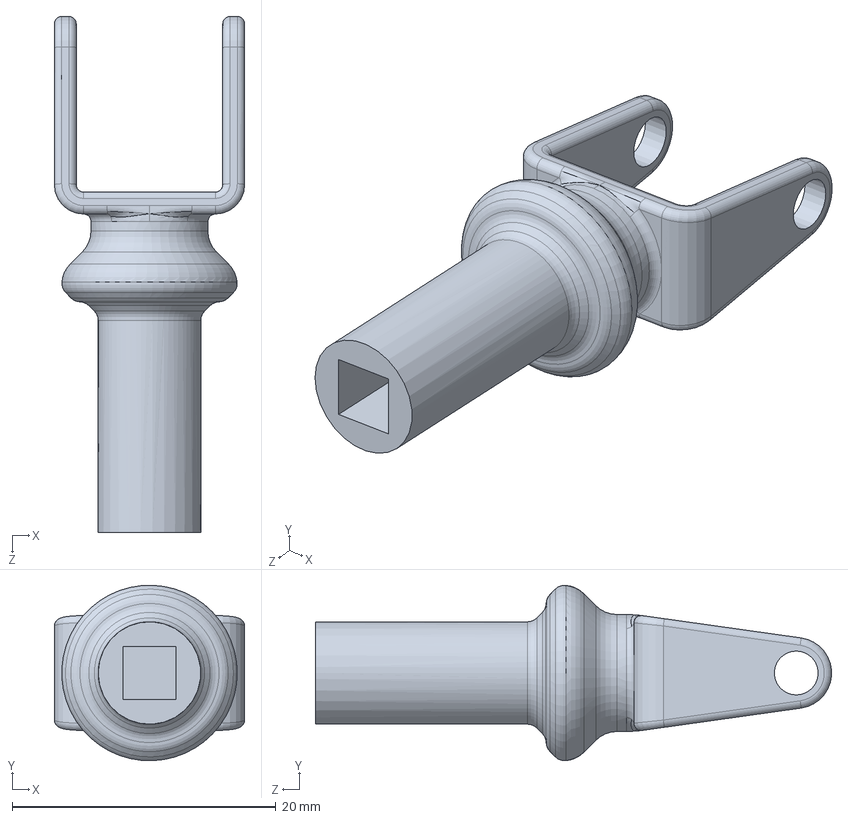
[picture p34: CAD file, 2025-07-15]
SOLIDWORKS Files/U-shaft/rwhubshaft2.SLDPRT
14.4 x 13.3 x 39.2 mm

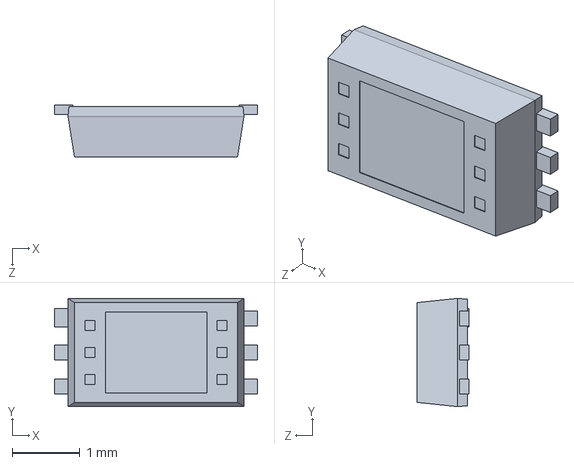
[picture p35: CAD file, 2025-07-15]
SOLIDWORKS Files/Enclosure/bh1750-module/Assign/BH1750.SLDPRT
3.00 x 1.60 x 0.77 mm

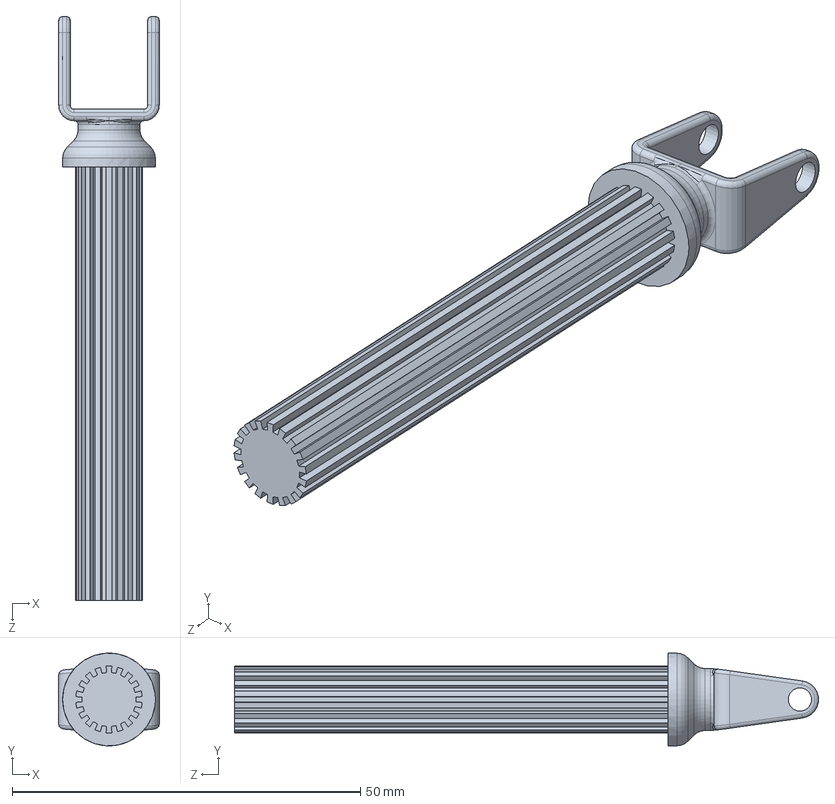
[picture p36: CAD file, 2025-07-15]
SOLIDWORKS Files/U-shaft/rwinnershaft.SLDPRT
14.4 x 13.3 x 83.9 mm

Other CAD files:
SOLIDWORKS Files/Enclosure/bh1750-module/BH1750_with_connector.STEP.SLDASM
SOLIDWORKS Files/Enclosure/bh1750-module/BH1750_with_connector.STEP
SOLIDWORKS Files/Enclosure/bh1750-module/Assign/PLS-5.SLDPRT
SOLIDWORKS Files/U-shaft/ujoint.SLDPRT
SOLIDWORKS Files/Enclosure/bh1750-module/Assign/BH1750_board.SLDPRT
SOLIDWORKS Files/Enclosure/bh1750-module/Assign/r_0603.SLDPRT
SOLIDWORKS Files/Enclosure/bh1750-module/BH1750_with_connector.SLDPRT
SOLIDWORKS Files/U-shaft/rwoutershaft.SLDPRT

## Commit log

2025-07-14 Add PCB file
    [LUMOS.PcbDoc, LUMOS.PrjPcb, LUMOS.SchDoc]
2026-08-09 Rename Folders
    [28BYJ-48.SLDPRT, BH1750.SLDPRT, BH1750_board.SLDPRT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]
2026-08-09 Initialize README with project details and setup
    Added comprehensive documentation for the LUMOS IoT-powered automated window blinds project, including features, system architecture, and setup instructions.
2026-08-09 Update README with images
    Replaced CAD image placeholders with actual images in the README.
2026-08-10 Enhance README with hardware specs and future plans
    Added hardware specifications, PCB design details, and future improvements to the README.
2026-08-10 Add PCB images
